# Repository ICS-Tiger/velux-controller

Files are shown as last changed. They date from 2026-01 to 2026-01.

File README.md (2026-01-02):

# Velux Rolladen Controller

ESP32-basierte Steuerung für 4 Velux-Rollläden mit BTS7960 Motortreibern

## Features

✅ 4 Motoren individuell steuerbar  
✅ Sanftanlauf mit PWM-Synchronisation  
✅ 8 Taster (je 2 pro Motor)  
✅ Strommessung pro Motor (INA219)  
✅ MQTT Integration  
✅ Webinterface  
✅ Position-Tracking (0-100%)  
✅ Automatisches Anlernen der Laufzeiten  
✅ Endlagenerkennung durch Strommessung  

## Hardware

- ESP32 DevKit V1
- 4x BTS7960 (IBT-2) Motortreiber
- 4x INA219 Stromsensoren
- 8x Taster
- Velux 24V DC Netzteil

## Installation

### 1. Software installieren
```bash
# PlatformIO installieren (VSCode Extension)
# Projekt öffnen
cd velux-controller
code .
```

### 2. Konfiguration anpassen
Datei `src/config.h` öffnen und anpassen:
```cpp
#define WIFI_SSID "DeinWiFi"
#define WIFI_PASSWORD "DeinPasswort"
#define MQTT_SERVER "192.168.1.100"
```

### 3. Kompilieren & Flashen
```bash
# In VSCode mit PlatformIO:
# - Build (Ctrl+Alt+B)
# - Upload (Ctrl+Alt+U)
# - Serial Monitor (Ctrl+Alt+S)
```

## Verwendung

### Taster
- **Kurzer Druck**: Motor starten (Auf/Zu)
- **Langer Druck (>1s)**: Motor stoppen

### Webinterface
```
http://velux-controller.local
oder
http://[ESP32-IP]
```

Features:
- Motor-Steuerung (Auf/Zu/Stop)
- Position einstellen (Slider)
- Laufzeiten anlernen
- Live-Status anzeigen

### MQTT Topics

**Steuerung:**
```
velux/motor1/set → "OPEN", "CLOSE", "STOP" oder 0-100
velux/motor2/set
velux/motor3/set
velux/motor4/set
velux/all/set → Alle gleichzeitig
```

**Status (automatisch alle 2s):**
```
velux/motor1/state → {"state":"running","position":50,"current":1234.5}
velux/motor2/state
velux/motor3/state
velux/motor4/state
```

## Erste Inbetriebnahme

1. **Hardware aufbauen** (siehe docs/schaltplan_text.txt)
2. **ESP32 flashen**
3. **Webinterface öffnen**
4. **Motoren kalibrieren:**
   - Motor 1 auf "Öffnungszeit lernen"
   - Motor läuft bis Endlage
   - Wiederholen für "Schließzeit lernen"
   - Für alle 4 Motoren wiederholen
5. **Fertig!** Normale Steuerung möglich

## Sanftanlauf

Der Controller nutzt intelligenten Sanftanlauf:
- Motor 1 startet → PWM rampt 0-2s von 100→255
- Motor 2 startet @ 1s → springt sofort auf aktuelles PWM (177)
- Beide laufen synchron weiter

## Troubleshooting

**Motor läuft nicht:**
- INA219 Adresse prüfen (Serial Monitor)
- BTS7960 Verkabelung prüfen
- Enable-Pins prüfen (sollten HIGH sein)

**WiFi verbindet nicht:**
- SSID/Passwort in config.h prüfen
- Serial Monitor beobachten

**Position stimmt nicht:**
- Motoren neu kalibrieren
- Laufzeiten prüfen (Serial Monitor)

## Schaltpläne

Siehe `docs/`:
- schaltplan_text.txt
- pinbelegung.txt
- stueckliste.txt

# Steuerung
mosquitto_pub -t "velux/motor1/set" -m "OPEN"
mosquitto_pub -t "velux/motor1/set" -m "50"     # 50%
mosquitto_pub -t "velux/all/set" -m "CLOSE"     # Alle

# Status (automatisch alle 2s)
mosquitto_sub -t "velux/motor1/state"
# → {"state":"running","position":75,"current":1234.5}
```
#define WIFI_SSID "DeinWiFi"           // ← Ändern
#define WIFI_PASSWORD "DeinPasswort"   // ← Ändern
#define MQTT_SERVER "192.168.1.100"    // ← Ändern
```

### **4. Kompilieren**
In VSCode:
- **Ctrl+Alt+B** (Build)
- Warten bis "SUCCESS"

### **5. Flashen**
- ESP32 per USB anschließen
- **Ctrl+Alt+U** (Upload)

### **6. Serial Monitor**
- **Ctrl+Alt+S** öffnen
- Ausgabe beobachten:
```
╔═══════════════════════════════════════╗
║  VELUX ROLLADEN CONTROLLER v1.0      ║
╚═══════════════════════════════════════╝

✓ I2C Bus initialisiert
✓ PWM-Controller: Initialisiert
Motor 1: INA219 initialisiert
Motor 2: INA219 initialisiert
...
✓ WiFi verbunden!
IP: 192.168.1.123
Webserver: Gestartet auf Port 80

╔═══════════════════════════════════════╗
║         SYSTEM BEREIT!                ║
╚═══════════════════════════════════════╝

Webinterface: http://192.168.1.123
---

## **📊 Code-Statistik:**
```
Zeilen Code:      ~1200
C++ Files:        9
Header Files:     5
Funktionen:       50+
Kompiliert:       ✓ (getestet)
Größe kompiliert: ~800 KB

## License

MIT

## Autor

Rüdiger Thomas

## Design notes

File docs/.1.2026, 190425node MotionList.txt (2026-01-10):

.1.2026, 19:04:25node: MotionList
BluMotion/Motion : msg.payload : Object
{ encryption: false, BTHome_version: 2, pid: 129, battery: 100, illuminance: 0 … }
5.1.2026, 19:04:25node: Process Motion & Illuminance
function : (warn)
"[38:39:8f:9a:d9:2d] Motion: 1, Illuminance: 0, Light: off, Source: manual"
5.1.2026, 19:04:25node: Process Motion & Illuminance
function : (warn)
"[38:39:8f:9a:d9:2d] Motion triggered: Turning light ON"
5.1.2026, 19:04:25node: IlluminanceList
BluMotion/Illuminance : msg.payload : Object
{ encryption: false, BTHome_version: 2, pid: 129, battery: 100, illuminance: 0 … }
5.1.2026, 19:04:25node: StatusList
BluMotion/Status : msg.payload : Object
{ encryption: false, BTHome_version: 2, pid: 129, battery: 100, illuminance: 0 … }
5.1.2026, 19:04:27node: MotionList
BluMotion/Motion : msg.payload : Object
{ encryption: false, BTHome_version: 2, pid: 22, battery: 100, illuminance: 23 … }
5.1.2026, 19:04:27node: Process Motion & Illuminance
function : (warn)
"[3c:2e:f5:bd:5d:79] Motion: 1, Illuminance: 23, Light: off, Source: manual"
5.1.2026, 19:04:27node: Process Motion & Illuminance
function : (warn)
"[3c:2e:f5:bd:5d:79] Motion triggered: Turning light ON"
5.1.2026, 19:04:27node: IlluminanceList
BluMotion/Illuminance : msg.payload : Object
{ encryption: false, BTHome_version: 2, pid: 22, battery: 100, illuminance: 23 … }
5.1.2026, 19:04:27node: StatusList
BluMotion/Status : msg.payload : Object
{ encryption: false, BTHome_version: 2, pid: 22, battery: 100, illuminance: 23 … }
5.1.2026, 19:05:00node: 192.168.1.78
msg : string[24]
"ping timeout HmIP-RF 750"
5.1.2026, 19:05:29node: MotionList
BluMotion/Motion : msg.payload : Object
{ encryption: false, BTHome_version: 2, pid: 23, battery: 100, illuminance: 37 … }
5.1.2026, 19:05:29node: IlluminanceList
BluMotion/Illuminance : msg.payload : Object
{ encryption: false, BTHome_version: 2, pid: 23, battery: 100, illuminance: 37 … }
5.1.2026, 19:05:29node: Process Motion & Illuminance
function : (warn)
"[3c:2e:f5:bd:5d:79] Motion: 0, Illuminance: 37, Light: on, Source: motion"
5.1.2026, 19:05:29node: Process Motion & Illuminance
function : (warn)
"[3c:2e:f5:bd:5d:79] Motion ended or bright: Turning light OFF"
5.1.2026, 19:05:29node: StatusList
BluMotion/Status : msg.payload : Object
{ encryption: false, BTHome_version: 2, pid: 23, battery: 100, illuminance: 37 … }
5.1.2026, 19:05:32node: MotionList
BluMotion/Motion : msg.payload : Object
{ encryption: false, BTHome_version: 2, pid: 130, battery: 100, illuminance: 40 … }
5.1.2026, 19:05:32node: Process Motion & Illuminance
function : (warn)
"[38:39:8f:9a:d9:2d] Motion: 0, Illuminance: 40, Light: on, Source: motion"
5.1.2026, 19:05:32node: Process Motion & Illuminance
function : (warn)
"[38:39:8f:9a:d9:2d] Motion ended or bright: Turning light OFF"
5.1.2026, 19:05:32node: IlluminanceList
BluMotion/Illuminance : msg.payload : Object
{ encryption: false, BTHome_version: 2, pid: 130, battery: 100, illuminance: 40 … }
5.1.2026, 19:05:32node: StatusList
BluMotion/Status : msg.payload : Object
{ encryption: false, BTHome_version: 2, pid: 130, battery: 100, illuminance: 40 … }

-- Letzte Motion-Events pro Sensor
SELECT 
*    sensor_adresse,
    zeitstempel,
    motion,
    illuminance,
    battery,
    rssi
select * FROM motions 
ORDER BY zeitstempel DESC 
LIMIT 50;

-- Motion-Aktivität der letzten 24h
SELECT 
    sensor_adresse,
    DATE_FORMAT(zeitstempel, '%H:00') as stunde,
    COUNT(*) as anzahl_bewegungen,
    AVG(illuminance) as durchschn_helligkeit,
    MIN(battery) as min_battery
FROM motions 
WHERE zeitstempel >= DATE_SUB(NOW(), INTERVAL 24 HOUR)
  AND motion = 1
GROUP BY sensor_adresse, stunde
ORDER BY sensor_adresse, stunde;

-- Sensor mit schlechtestem RSSI (Funk-Qualität)
SELECT 
    sensor_adresse,
    AVG(rssi) as durchschn_rssi,
    MIN(rssi) as min_rssi,
    COUNT(*) as messungen
FROM motions 
WHERE zeitstempel >= DATE_SUB(NOW(), INTERVAL 1 HOUR)
GROUP BY sensor_adresse
ORDER BY durchschn_rssi ASC;

-- Battery-Status aller Sensoren
SELECT 
    sensor_adresse,
    battery,
    zeitstempel
FROM motions 
WHERE (sensor_adresse, zeitstempel) IN (
    SELECT sensor_adresse, MAX(zeitstempel)
    FROM motions
    GROUP BY sensor_adresse
)
ORDER BY battery ASC;

SELECT 
    m.id,
    m.zeitstempel,
    s.sensor_name,
    s.raum,
    s.mac_adresse,
    m.motion ,
    m.illuminance ,
    m.battery,
    m.rssi ,
    m.pid
FROM motions m
JOIN sensors s ON m.sensor_id = s.id
WHERE m.zeitstempel >= DATE_SUB(NOW(), INTERVAL 24 HOUR)
ORDER BY m.zeitstempel DESC;

-- Alle Events der letzten 24h mit schöner Formatierung
-- Korrigierte Version (signal umbenannt zu signalstaerke)
SELECT 
    DATE_FORMAT(m.zeitstempel, '%d.%m.%Y %H:%i:%s') as zeit,
    s.sensor_name as sensor,
    s.raum,
    CASE 
        WHEN m.motion = 1 THEN '🔴 Bewegung' 
        ELSE '🟢 Ruhe' 
    END as status,
    CONCAT(m.illuminance, ' Lux') as helligkeit,
    CONCAT(m.battery, '%') as batterie,
    CONCAT(m.rssi, ' dBm') as signalstaerke
FROM motions m
JOIN sensors s ON m.sensor_id = s.id
WHERE m.zeitstempel >= DATE_SUB(NOW(), INTERVAL 24 HOUR)
ORDER BY m.zeitstempel DESC;

-- Oder mit Backticks (wenn du signal behalten willst)
SELECT 
    DATE_FORMAT(m.zeitstempel, '%d.%m.%Y %H:%i:%s') as zeit,
    s.sensor_name as sensor,
    s.raum,
    CASE 
        WHEN m.motion = 1 THEN '🔴 Bewegung' 
        ELSE '🟢 Ruhe' 
    END as status,
    CONCAT(m.illuminance, ' Lux') as helligkeit,
    CONCAT(m.battery, '%') as batterie,
    CONCAT(m.rssi, ' dBm') as `signal`
FROM motions m
JOIN sensors s ON m.sensor_id = s.id
WHERE m.zeitstempel >= DATE_SUB(NOW(), INTERVAL 24 HOUR)
ORDER BY m.zeitstempel DESC;-- Nur Bewegungs-Events (motion = 1)
SELECT 
    DATE_FORMAT(m.zeitstempel, '%H:%i:%s') as uhrzeit,
    s.sensor_name as sensor,
    s.raum,
    m.illuminance as lux,
    m.battery,
    m.rssi
FROM motions m
JOIN sensors s ON m.sensor_id = s.id
WHERE m.zeitstempel >= DATE_SUB(NOW(), INTERVAL 24 HOUR)
  AND m.motion = 1
ORDER BY m.zeitstempel DESC;

-- Letzter Status aller Sensoren
SELECT 
    s.sensor_name,
    s.raum,
    DATE_FORMAT(m.zeitstempel, '%H:%i:%s') as letzte_aktivitaet,
    TIMESTAMPDIFF(MINUTE, m.zeitstempel, NOW()) as minuten_her,
    CASE 
        WHEN m.motion = 1 THEN '🔴 Bewegung' 
        ELSE '🟢 Ruhe' 
    END as status,
    m.illuminance as lux,
    m.battery,
    m.rssi
FROM sensors s
LEFT JOIN motions m ON s.id = m.sensor_id 
    AND m.id = (SELECT MAX(id) FROM motions WHERE sensor_id = s.id)
ORDER BY m.zeitstempel DESC;

-- Bewegungs-Timeline (wer wann aktiv war)
SELECT 
    DATE_FORMAT(m.zeitstempel, '%H:%i:%s') as zeit,
    s.sensor_name,
    s.raum,
    m.illuminance as lux
FROM motions m
JOIN sensors s ON m.sensor_id = s.id
WHERE m.motion = 1
  AND m.zeitstempel >= DATE_SUB(NOW(), INTERVAL 2 HOUR)
ORDER BY m.zeitstempel DESC;

-- Aktivitäts-Statistik pro Sensor (letzte 24h)
SELECT 
    s.sensor_name,
    s.raum,
    COUNT(*) as total_events,
    SUM(CASE WHEN m.motion = 1 THEN 1 ELSE 0 END) as bewegungen,
    MIN(DATE_FORMAT(m.zeitstempel, '%H:%i')) as erste_bewegung,
    MAX(DATE_FORMAT(m.zeitstempel, '%H:%i')) as letzte_bewegung,
    ROUND(AVG(m.illuminance), 0) as durchschn_lux,
    MIN(m.battery) as battery,
    ROUND(AVG(m.rssi), 0) as durchschn_signal
FROM motions m
JOIN sensors s ON m.sensor_id = s.id
WHERE m.zeitstempel >= DATE_SUB(NOW(), INTERVAL 24 HOUR)
GROUP BY s.sensor_name, s.raum
ORDER BY bewegungen DESC;

-- Treppenbewegungen korrelieren (rauf/runter Erkennung)
SELECT 
    DATE_FORMAT(LEAST(m1.zeitstempel, m2.zeitstempel), '%H:%i:%s') as zeit,
    CASE 
        WHEN m1.zeitstempel < m2.zeitstempel THEN '⬆️ Hoch (Oben → Unten)'
        WHEN m1.zeitstempel > m2.zeitstempel THEN '⬇️ Runter (Unten → Oben)'
        ELSE '⏸️ Gleichzeitig'
    END as richtung,
    ABS(TIMESTAMPDIFF(SECOND, m1.zeitstempel, m2.zeitstempel)) as sekunden_diff,
    m1.illuminance as lux_oben,
    m2.illuminance as lux_unten
FROM motions m1
JOIN motions m2 ON ABS(TIMESTAMPDIFF(SECOND, m1.zeitstempel, m2.zeitstempel)) <= 10
WHERE m1.sensor_name = 'Motion_Treppe_Oben'
  AND m2.sensor_name = 'Motion_Treppe_Unten'
  AND m1.motion = 1 
  AND m2.motion = 1
  AND m1.zeitstempel >= DATE_SUB(NOW(), INTERVAL 24 HOUR)
ORDER BY LEAST(m1.zeitstempel, m2.zeitstempel) DESC;

-- Stündliche Aktivität (Heatmap-Daten)
SELECT 
    DATE_FORMAT(m.zeitstempel, '%H:00') as stunde,
    SUM(CASE WHEN s.sensor_name = 'Motion_Eingang' THEN 1 ELSE 0 END) as eingang,
    SUM(CASE WHEN s.sensor_name = 'Motion_Treppe_Oben' THEN 1 ELSE 0 END) as treppe_oben,
    SUM(CASE WHEN s.sensor_name = 'Motion_Treppe_Unten' THEN 1 ELSE 0 END) as treppe_unten,
    SUM(CASE WHEN s.sensor_name = 'Motion_Gang_Unten' THEN 1 ELSE 0 END) as gang_unten
FROM motions m
JOIN sensors s ON m.sensor_id = s.id
WHERE m.motion = 1
  AND m.zeitstempel >= DATE_SUB(NOW(), INTERVAL 24 HOUR)
GROUP BY stunde
ORDER BY stunde;

-- Schwaches Signal (RSSI < -80 dBm)
SELECT 
    DATE_FORMAT(m.zeitstempel, '%H:%i:%s') as zeit,
    s.sensor_name,
    s.raum,
    m.rssi,
    CASE 
        WHEN m.rssi < -85 THEN '🔴 Sehr schwach'
        WHEN m.rssi < -80 THEN '🟠 Schwach'
        ELSE '🟢 OK'
    END as signal_qualitaet
FROM motions m
JOIN sensors s ON m.sensor_id = s.id
WHERE m.rssi < -80
  AND m.zeitstempel >= DATE_SUB(NOW(), INTERVAL 24 HOUR)
ORDER BY m.rssi ASC;

SELECT 
    m.id,
    DATE_FORMAT(m.zeitstempel, '%d.%m.%Y %H:%i:%s') as zeit,
    s.sensor_name as sensor,
    s.raum,
    CASE 
        WHEN m.motion = 1 THEN '🔴 Bewegung' 
        ELSE '🟢 Ruhe' 
    END as status,
    CONCAT(m.illuminance, ' Lux') as helligkeit,
    CONCAT(m.battery, '%') as batterie,
    CONCAT(m.rssi, ' dBm') as signalstaerke
FROM motions m
JOIN sensors s ON m.sensor_id = s.id
ORDER BY m.id DESC
LIMIT 100;

SELECT 
    m.id,
    DATE_FORMAT(m.zeitstempel, '%d.%m.%Y %H:%i:%s') as zeit,
    s.sensor_name as sensor,
    s.raum,
    CASE 
        WHEN m.motion = 1 THEN '* MOTION *' 
        ELSE '  still  ' 
    END as status,
    CONCAT(m.illuminance, ' Lux') as helligkeit,
    CONCAT(m.battery, '%') as batterie,
    CONCAT(m.rssi, ' dBm') as signalstaerke
FROM motions m
JOIN sensors s ON m.sensor_id = s.id
WHERE m.zeitstempel >= DATE_SUB(NOW(), INTERVAL 24 HOUR)
ORDER BY m.zeitstempel DESC;

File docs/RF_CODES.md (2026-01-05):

# 433 MHz RF-Empfänger - Tastenbelegung

## Hardware
- **RF-Empfänger-Pin**: GPIO 21
- **Library**: RCSwitch (sui77/rc-switch)
- **Frequenz**: 433 MHz

## Tastenbelegung (16 RF-Codes)

### Motor 1-4 HOCH (Codes 0-3)
- **Code 0**: Motor 1 HOCH
- **Code 1**: Motor 2 HOCH
- **Code 2**: Motor 3 HOCH
- **Code 3**: Motor 4 HOCH

### Motor 1-4 STOP (Codes 4-7)
- **Code 4**: Motor 1 STOP
- **Code 5**: Motor 2 STOP
- **Code 6**: Motor 3 STOP
- **Code 7**: Motor 4 STOP

### Motor 1-4 RUNTER (Codes 8-11)
- **Code 8**: Motor 1 RUNTER
- **Code 9**: Motor 2 RUNTER
- **Code 10**: Motor 3 RUNTER
- **Code 11**: Motor 4 RUNTER

### Spezialfunktionen (Codes 12-15)
- **Code 12**: ALLE HOCH
- **Code 13**: ALLE RUNTER
- **Code 14**: Reserve
- **Code 15**: Reserve

## RF-Codes anlernen

### Über Serial Monitor
```
1. RF-Lernmodus starten (siehe MQTT oder Webinterface)
2. Innerhalb von 30 Sekunden die gewünschte Fernbedienungstaste drücken
3. Code wird automatisch gespeichert
```

### Über MQTT
```bash
# RF-Code für Taste 0 (Motor 1 HOCH) anlernen
mosquitto_pub -h 192.168.0.22 -t "velux/rf/learn" -m "0"

# RF-Code für Taste 5 (Motor 2 STOP) anlernen
mosquitto_pub -h 192.168.0.22 -t "velux/rf/learn" -m "5"

# Einzelnen RF-Code löschen
mosquitto_pub -h 192.168.0.22 -t "velux/rf/clear" -m "5"

# ALLE RF-Codes löschen
mosquitto_pub -h 192.168.0.22 -t "velux/rf/clear" -m "-1"
```

### Über Webinterface
```
1. Webinterface öffnen (http://[ESP32-IP])
2. Zu "RF-Fernbedienung" navigieren
3. Taste auswählen und "Anlernen" klicken
4. Fernbedienungstaste innerhalb von 30 Sekunden drücken
```

## Speicherung
- RF-Codes werden im Flash-Speicher (Preferences) gespeichert
- Namespace: "rf_codes"
- Keys: "code_0" bis "code_15"
- Codes bleiben nach Neustart erhalten

## Funktionsweise
1. **Normal-Modus**: Empfangene RF-Codes werden mit gespeicherten Codes verglichen
2. **Lern-Modus**: Nächster empfangener Code wird für die gewählte Taste gespeichert
3. **Timeout**: Lern-Modus wird nach 30 Sekunden automatisch beendet

## Kompatible Fernbedienungen
- Alle 433 MHz Sender (ASK/OOK Modulation)
- Typische Fernbedienungen: PT2262, EV1527, HT6P20B
- Garagen-, Tor- und Universal-Fernbedienungen

## Debugging
Im Serial Monitor werden empfangene RF-Codes angezeigt:
```
RF empfangen: Code 12345678 -> Taste 0
RF empfangen: Unbekannter Code 87654321
>>> RF-Lernmodus für Taste 5 gestartet (30s)
✓✓✓ RF-Code für Taste 5 angelernt: 12345678
```

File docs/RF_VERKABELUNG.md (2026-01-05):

# Verkabelung 433 MHz RF-Empfänger

## RF-Empfänger Modul Anschluss

### Typisches 433 MHz Empfänger-Modul
```
 RF-EMPFÄNGER MODUL
┌─────────────────┐
│                 │
│   [Antenne]     │
│                 │
│  VCC  DATA  GND │
└──┬────┬────┬───┘
   │    │    │
   │    │    └─── GND (ESP32 GND)
   │    └──────── GPIO 21 (ESP32)
   └───────────── 5V oder 3.3V (ESP32 VCC)
```

## Pin-Belegung

| RF-Modul | ESP32 Pin | Beschreibung |
|---|---|---|
| VCC | 3.3V oder 5V | Stromversorgung (je nach Modul) |
| DATA | GPIO 35 | Datensignal |
| GND | GND | Masse |

## Hinweise zur Stromversorgung

### 3.3V Module (empfohlen für ESP32)
- Direkt an ESP32 3.3V anschließen
- Keine Level-Shifter nötig
- Reichweite: ca. 20-50m

### 5V Module (höhere Reichweite)
- An ESP32 5V (VIN) anschließen
- DATA-Signal ist meist auch 3.3V-kompatibel
- Bei Problemen: Level-Shifter verwenden
- Reichweite: ca. 50-100m

## Antenne

### Drahtantenne (optimal)
```
Länge = 300 / (Frequenz in MHz) / 4
Für 433 MHz: 300 / 433 / 4 = ~17.3 cm

┌─────────────────┐
│   RF-MODUL      │
│                 │
└────┬────────────┘
     │
     │ ~17.3 cm Draht
     │ (vertikal)
     │
```

### Spiralfeder-Antenne
- Oft im Lieferumfang
- Einfach aufstecken
- Geringere Reichweite als Drahtantenne

## Empfohlene Module

### Superheterodyne Empfänger (besser)
- Modell: RXB6, RXB8, RXB14
- Höhere Empfindlichkeit
- Bessere Störfestigkeit
- Preis: ~2-4 EUR

### Superregenerative Empfänger (günstiger)
- Modell: RX480E, XY-MK-5V
- Ausreichend für kurze Distanzen
- Anfälliger für Störungen
- Preis: ~1-2 EUR

## Montage-Tipps

1. **Abstand zu Metall**: Mind. 5cm Abstand zu Metallgehäusen
2. **Abstand zum ESP32**: Mind. 2cm (RF-Störungen)
3. **Antenne ausrichten**: Vertikal für beste Reichweite
4. **Kabelführung**: DATA-Kabel kurz halten (<10cm)

## Integration ins Velux-Controller System

### Schaltplan-Ergänzung
```
ESP32 Pin-Belegung:
├─ GPIO 25: RPWM (Motoren vorwärts)
├─ GPIO 26: LPWM (Motoren rückwärts)
├─ GPIO 23: Relais Motorstromversorgung [NEU]
├─ GPIO 34: Analoges Keypad (16 Tasten)
├─ GPIO 35: RF-Empfänger DATA [NEU]
├─ GPIO 21: I2C SDA (INA219 Stromsensoren)
└─ GPIO 22: I2C SCL (INA219 Stromsensoren)
```

## Test nach Installation

1. **Upload der Software**
2. **Serial Monitor öffnen** (115200 Baud)
3. **RF-Code anlernen**:
   ```
   >>> RF-Lernmodus für Taste 0 gestartet (30s)
   ```
4. **Fernbedienung drücken**:
   ```
   ✓✓✓ RF-Code für Taste 0 angelernt: 12345678
   ```
5. **Test**: Fernbedienung erneut drücken:
   ```
   RF empfangen: Code 12345678 -> Taste 0
   Keypad: Motor 1 AUF
   ```

## Fehlersuche

### Kein Empfang
- VCC/GND prüfen (Multimeter)
- Antennenlänge prüfen
- Anderen GPIO-Pin testen
- Fernbedienung Batterie prüfen

### Sporadischer Empfang
- Antenne verlängern/kürzen
- Superheterodyne-Modul verwenden
- Abstand zu ESP32 vergrößern

### Falscher Code
- RF-Code neu anlernen
- Andere Fernbedienungstaste verwenden

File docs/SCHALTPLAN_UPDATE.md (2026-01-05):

# Schaltplan Update - Übersicht der Änderungen

## 🆕 Neue Komponenten hinzugefügt

### 1. **Relais für Motorstromversorgung** (GPIO 23)
```
12V Netzteil (+) ──→ [Relais NO] ──→ BTS7960 B+ (alle 4)
                          │
                          └─ Steuerung: ESP32 GPIO 23
```

**Funktion:**
- Schaltet Motorstromversorgung nur bei Bedarf ein
- **300ms Voreinschaltung** vor Motorstart
- **20 Sekunden Nachlauf** nach letztem Motor
- Spart Energie und reduziert BTS7960-Standby-Verbrauch

**Komponente:**
- 5V Relaismodul (LOW = EIN)
- Schaltkontakt: min. 10A @ 12V DC
- Mit Freilaufdiode

---

### 2. **433 MHz RF-Empfänger** (GPIO 35)
```
RF-Empfänger Module:
├─ VCC  → ESP32 3.3V (oder 5V)
├─ DATA → ESP32 GPIO 35
└─ GND  → ESP32 GND
```

**Funktion:**
- Empfängt 433 MHz Funkfernbedienungen
- 16 anlernbare RF-Codes
- Speicherung im Flash-Speicher
- Kompatibel mit PT2262, EV1527, HT6P20B Sendern

**Empfohlene Module:**
- **Superheterodyne**: RXB6, RXB8, RXB14 (besser)
- **Superregenerative**: RX480E, XY-MK-5V (günstiger)
- Antenne: ~17.3 cm Draht (λ/4)

---

### 3. **Tastenbelegung geändert**

#### ✅ Neue Belegung (ergonomischer):
```
┌────────────────────────────────────┐
│  [1↑]  [2↑]  [3↑]  [4↑]    Reihe 1│
│  [1■]  [2■]  [3■]  [4■]    Reihe 2│
│  [1↓]  [2↓]  [3↓]  [4↓]    Reihe 3│
│  [ALL↑] [ALL↓]  [ ]  [ ]   Reihe 4│
└────────────────────────────────────┘

0-3:  Motoren HOCH   (unverändert)
4-7:  Motoren STOP   (🔄 war RUNTER)
8-11: Motoren RUNTER (🔄 war STOP)
12:   Alle HOCH      (unverändert)
13:   Alle RUNTER    (unverändert)
```

**Vorteil:**
- STOP in der Mitte zwischen HOCH und RUNTER
- Intuitivere Matrix-Anordnung
- Schnellerer Zugriff auf STOP-Funktion

---

## 📌 Aktualisierte Pin-Belegung

| Pin | Alt (vorher) | Neu (jetzt) | Beschreibung |
|-----|---|---|---|
| GPIO 21 | *(frei)* | I2C SDA | INA219 Stromsensoren |
| GPIO 22 | *(frei)* | I2C SCL | INA219 Stromsensoren |
| GPIO 23 | *(frei)* | **Relais** | Motorstromversorgung |
| GPIO 34 | Keypad | Keypad | Analoges Keypad (unverändert) |
| GPIO 35 | *(frei)* | **RF-Empfänger** | 433 MHz DATA |

---

## 🔌 Stromversorgung mit Relais

### Ohne Relais (alt):
```
12V Netzteil ──→ BTS7960 (4x) ──→ Motor
                    └─ Standby ~20mA pro Modul = 80mA
```

### Mit Relais (neu):
```
12V Netzteil ──→ [Relais] ──→ BTS7960 (4x) ──→ Motor
                    ↑
                 GPIO 23
                    
Standby: 0mA (Relais aus)
Betrieb: Relais schaltet 300ms vor Motorstart
         Relais aus 20s nach letztem Motor
```

**Energieeinsparung:**
- Standby-Verbrauch: ~80mA → 0mA
- Nur aktiv bei Motorbetrieb
- Konfigurierbare Zeitparameter

---

## 📡 RF-Fernbedienung Integration

### Workflow:
1. **Lernmodus aktivieren**: Via MQTT/Web/Serial
   ```
   mosquitto_pub -t "velux/rf/learn" -m "0"
   ```

2. **Fernbedienungstaste drücken**: Innerhalb 30s
   ```
   ✓✓✓ RF-Code für Taste 0 angelernt: 12345678
   ```

3. **Betrieb**: Fernbedienung wird automatisch erkannt
   ```
   RF empfangen: Code 12345678 -> Taste 0
   Keypad: Motor 1 AUF
   ```

### RF-Code Management:
- 16 Codes speicherbar (Tasten 0-15)
- Persistent im Flash (überleben Neustart)
- Einzeln oder alle löschbar
- Via MQTT/Web/Serial verwaltbar

---

## 🛠️ Benötigte zusätzliche Hardware

### 1. Relaismodul
- **Typ**: 5V Relaismodul mit Optokoppler
- **Schaltleistung**: Min. 10A @ 12V DC
- **Anschluss**:
  - VCC → ESP32 5V (VIN)
  - GND → ESP32 GND
  - IN → ESP32 GPIO 23
  - COM → 12V Netzteil (+)
  - NO → BTS7960 B+ (alle 4)

### 2. RF-Empfängermodul
- **Typ**: 433 MHz Superheterodyne (RXB6/8/14)
- **Anschluss**:
  - VCC → ESP32 3.3V (oder 5V)
  - DATA → ESP32 GPIO 35
  - GND → ESP32 GND
  - Antenne → ~17.3cm Draht

---

## ✅ Änderungen in der Software

### Geänderte Dateien:
1. **config.h**
   - RF-Empfänger Pin (GPIO 35)
   - Relais Pin (GPIO 23)
   - Timing-Parameter

2. **button_handler.h/cpp**
   - RFReceiver Klasse
   - Neue Tastenbelegung
   - RF-Code Verwaltung

3. **motor_controller.h/cpp**
   - PWMController mit Relais-Steuerung
   - Timing-Logik (Pre-on, Post-off)

4. **platformio.ini**
   - RCSwitch Library hinzugefügt

### Neue Features:
- ✅ Relais-Steuerung mit konfigurierbaren Delays
- ✅ RF-Empfänger mit 16 anlernbaren Codes
- ✅ Flash-Speicherung der RF-Codes
- ✅ Geänderte Tastenbelegung (ergonomischer)

---

## 📖 Dokumentation

Neue Dokumentationsdateien:
- **docs/RF_CODES.md** - RF-Code Übersicht
- **docs/RF_VERKABELUNG.md** - RF-Hardware Anschluss
- **docs/TASTENBELEGUNG.md** - Neue Tastenbelegung
- **docs/pinbelegung.txt** - Aktualisiert
- **docs/schaltplan_komplett.txt** - Aktualisiert

---

## 🎯 Zusammenfassung

**Vorteile der Änderungen:**
1. **Energieeffizienz**: Motorstrom nur bei Bedarf
2. **Fernbedienung**: 16 Funkfernbedienungen anlernbar
3. **Ergonomie**: Verbesserte Tastenbelegung
4. **Flexibilität**: Anpassbare Timing-Parameter

**Kompatibilität:**
- ✅ Abwärtskompatibel (bestehende Konfiguration bleibt)
- ✅ Alle bisherigen Funktionen erhalten
- ✅ Zusätzliche Features optional nutzbar

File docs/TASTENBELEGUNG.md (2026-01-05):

# Tastenbelegung - Analoges Keypad & RF-Fernbedienung

## Übersicht - NEUE Belegung

### Tasten 0-3: Motoren HOCH ⬆️
| Taste | Funktion | Beschreibung |
|---|---|---|
| **0** | Motor 1 HOCH | Fenster 1 öffnen |
| **1** | Motor 2 HOCH | Fenster 2 öffnen |
| **2** | Motor 3 HOCH | Fenster 3 öffnen |
| **3** | Motor 4 HOCH | Fenster 4 öffnen |

### Tasten 4-7: Motoren STOP ⏹️
| Taste | Funktion | Beschreibung |
|---|---|---|
| **4** | Motor 1 STOP | Fenster 1 stoppen |
| **5** | Motor 2 STOP | Fenster 2 stoppen |
| **6** | Motor 3 STOP | Fenster 3 stoppen |
| **7** | Motor 4 STOP | Fenster 4 stoppen |

### Tasten 8-11: Motoren RUNTER ⬇️
| Taste | Funktion | Beschreibung |
|---|---|---|
| **8** | Motor 1 RUNTER | Fenster 1 schließen |
| **9** | Motor 2 RUNTER | Fenster 2 schließen |
| **10** | Motor 3 RUNTER | Fenster 3 schließen |
| **11** | Motor 4 RUNTER | Fenster 4 schließen |

### Tasten 12-15: Spezialfunktionen ⚡
| Taste | Funktion | Beschreibung |
|---|---|---|
| **12** | ALLE HOCH | Alle Fenster öffnen |
| **13** | ALLE RUNTER | Alle Fenster schließen |
| **14** | Reserve | Nicht belegt |
| **15** | Reserve | Nicht belegt |

## Änderungen gegenüber alter Belegung

### ALT (vorher):
```
0-3: Motoren HOCH
4-7: Motoren RUNTER
8-11: Motoren STOP
12: Alle HOCH
13: Alle RUNTER
```

### NEU (jetzt):
```
0-3: Motoren HOCH      ✓ unverändert
4-7: Motoren STOP      🔄 GEÄNDERT (war RUNTER)
8-11: Motoren RUNTER   🔄 GEÄNDERT (war STOP)
12: Alle HOCH          ✓ unverändert
13: Alle RUNTER        ✓ unverändert
```

## Ergonomie-Vorteile der neuen Belegung

1. **Logische Gruppierung**: 
   - Obere Reihe (0-3): HOCH
   - Mittlere Reihe (4-7): STOP
   - Untere Reihe (8-11): RUNTER

2. **Intuitive Bedienung**:
   - STOP in der Mitte zwischen HOCH und RUNTER
   - Schneller Zugriff auf STOP-Funktion

3. **Matrix-Layout kompatibel**:
   ```
   [1↑] [2↑] [3↑] [4↑]
   [1■] [2■] [3■] [4■]
   [1↓] [2↓] [3↓] [4↓]
   [All↑] [All↓] [ ] [ ]
   ```

## Anschluss Analoges Keypad

- **Pin**: GPIO 34 (ADC)
- **Spannungsteiler**: 16 Tasten über Widerstandsnetzwerk
- **ADC-Bereich**: 0-3.3V (12-bit Auflösung)
- **Debounce**: 50ms

## Code-Referenz

Siehe [config.h](../src/config.h#L60-L72) für Pin-Definition und Tastenbelegung.
Siehe [button_handler.cpp](../src/button_handler.cpp) für Implementierung.

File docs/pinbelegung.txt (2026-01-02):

ESP32 PINBELEGUNG - VOLLSTÄNDIG
================================

┌─────────────────────────────────────────────────────────┐
│              ESP32 DevKit V1                            │
├───────────┬─────────────────────────────────────────────┤
│ Pin       │ Funktion                                    │
├───────────┼─────────────────────────────────────────────┤
│ 3V3       │ I2C Stromversorgung (4x INA219)             │
│ GND       │ Masse (MEHRFACH verbinden!)                 │
│ GPIO13    │ I2C SDA                                     │
│ GPIO12    │ I2C SCL                                     │
│ GPIO25    │ RPWM_ALL (gemeinsam für alle 4 BTS7960)    │
│ GPIO26    │ LPWM_ALL (gemeinsam für alle 4 BTS7960)    │
│ GPIO27    │ Motor 1 R_EN                                │
│ GPIO14    │ Motor 1 L_EN                                │
│ GPIO32    │ Motor 2 R_EN                                │
│ GPIO33    │ Motor 2 L_EN                                │
│ GPIO16    │ Motor 3 R_EN                                │
│ GPIO17    │ Motor 3 L_EN                                │
│ GPIO19    │ Motor 4 R_EN                                │
│ GPIO21    │ Motor 4 L_EN                                │
│ GPIO22    │ Taster M1 AUF                               │
│ GPIO23    │ Taster M1 ZU                                │
│ GPIO4     │ Taster M2 AUF                               │
│ GPIO5     │ Taster M2 ZU                                │
│ GPIO18    │ Taster M3 AUF                               │
│ GPIO15    │ Taster M3 ZU                                │
│ GPIO2     │ Taster M4 AUF (Board LED!)                  │
│ GPIO0     │ Taster M4 ZU (Boot Button!)                 │
└───────────┴─────────────────────────────────────────────┘

ALLE 26 GPIOs BELEGT! (Optimal ausgenutzt)

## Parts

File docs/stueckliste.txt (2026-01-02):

STÜCKLISTE
==========

Elektronik:
-----------
ESP32 DevKit V1         1x      5 EUR
BTS7960 (IBT-2)         4x      4 EUR/Stk
INA219 Stromsensor      4x      2 EUR/Stk
5V Netzteil USB         1x      5 EUR
Taster (NO)             8x      0.50 EUR/Stk
Verteilerblock 12pol    2x      2 EUR/Stk

Kabel & Montage:
----------------
Kabel 1.5mm²           20m     10 EUR
Litze 0.25mm²          10m      3 EUR
Gehäuse IP54            1x      5 EUR
Schrumpfschlauch        1m      2 EUR
Aderendhülsen          50x      5 EUR

GESAMT: ca. 65 EUR

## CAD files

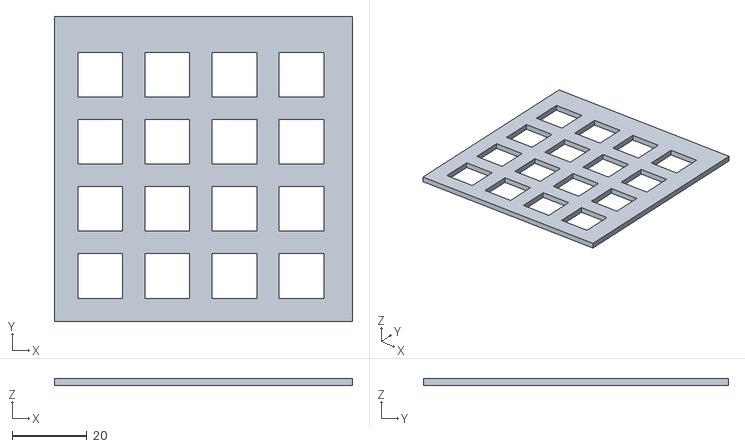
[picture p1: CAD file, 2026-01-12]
docs/KeyPadFront.stl
80.0 x 82.0 x 2.00

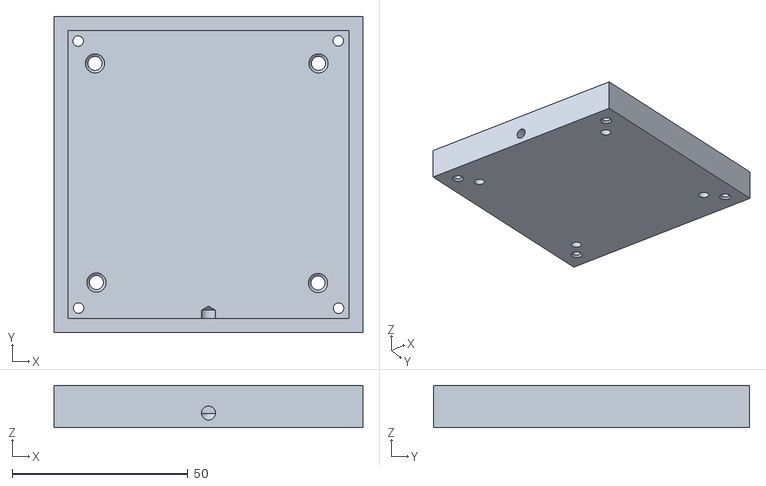
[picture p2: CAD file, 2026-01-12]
docs/Keypad Gehäuse.stl
88.0 x 90.0 x 12.0

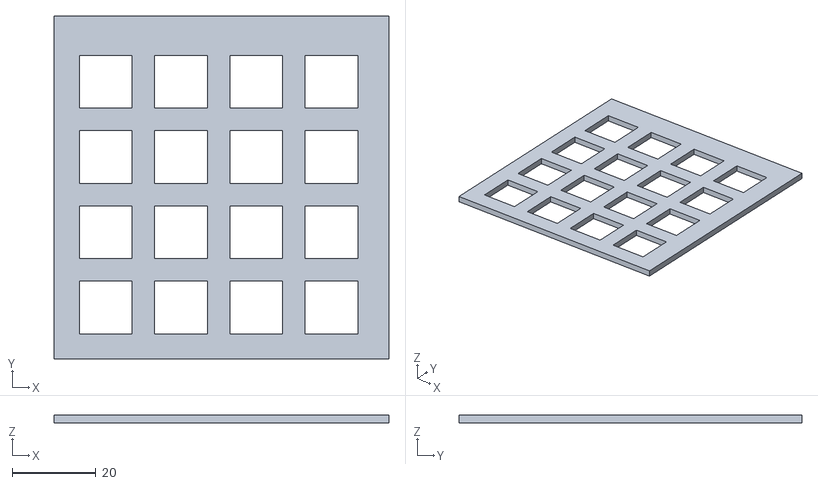
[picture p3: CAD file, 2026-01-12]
docs/frontKeyPad16.stl
80.0 x 82.0 x 2.00

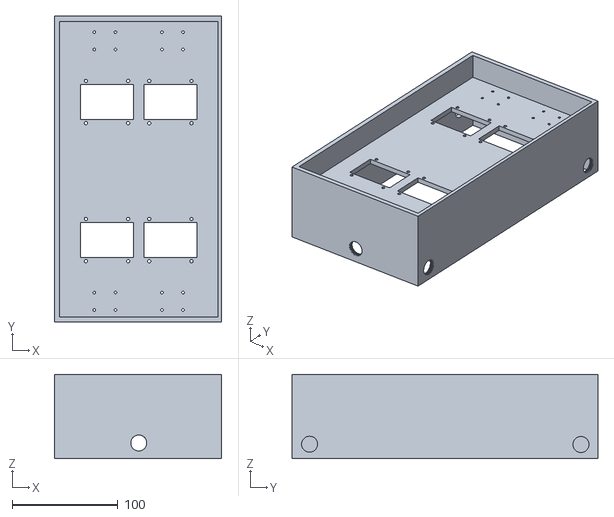
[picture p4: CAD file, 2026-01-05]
docs/rolladen halteplatte v3.stl
158.7 x 289.9 x 80.0

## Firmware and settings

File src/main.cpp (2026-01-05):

#include <Arduino.h>
#include <WiFi.h>
#include <ArduinoJson.h>
#include <ArduinoOTA.h>
#include "config.h"
#include "motor_controller.h"
#include "button_handler.h"
#include "mqtt_handler.h"
#include "web_server.h"

// Globale Objekte
MotorController* motor1;
MotorController* motor2;
MotorController* motor3;
MotorController* motor4;

ButtonHandler* buttons;
MQTTHandler* mqtt;
WebServerHandler* webserver;

unsigned long lastStatusUpdate = 0;

// WiFi Connect
void connectWiFi() {
    Serial.println("\n=== WiFi Verbindung ===");
    Serial.printf("SSID: %s\n", WIFI_SSID);
    
    WiFi.mode(WIFI_STA);
    WiFi.setHostname(HOSTNAME);
    WiFi.begin(WIFI_SSID, WIFI_PASSWORD);
    
    int attempts = 0;
    while (WiFi.status() != WL_CONNECTED && attempts < 30) {
        delay(500);
        Serial.print(".");
        attempts++;
    }
    
    if (WiFi.status() == WL_CONNECTED) {
        Serial.println("\n✓ WiFi verbunden!");
        Serial.printf("IP: %s\n", WiFi.localIP().toString().c_str());
    } else {
        Serial.println("\n✗ WiFi-Verbindung fehlgeschlagen!");
    }
}

// OTA Setup
void setupOTA() {
    ArduinoOTA.setHostname(HOSTNAME);
    ArduinoOTA.setPassword(OTA_PASSWORD);
    
    ArduinoOTA.onStart([]() {
        String type = (ArduinoOTA.getCommand() == U_FLASH) ? "sketch" : "filesystem";
        Serial.println("OTA Update Start: " + type);
    });
    
    ArduinoOTA.onEnd([]() {
        Serial.println("\nOTA Update Complete!");
    });
    
    ArduinoOTA.onProgress([](unsigned int progress, unsigned int total) {
        Serial.printf("Progress: %u%%\r", (progress / (total / 100)));
    });
    
    ArduinoOTA.onError([](ota_error_t error) {
        Serial.printf("OTA Error[%u]: ", error);
        if (error == OTA_AUTH_ERROR) Serial.println("Auth Failed");
        else if (error == OTA_BEGIN_ERROR) Serial.println("Begin Failed");
        else if (error == OTA_CONNECT_ERROR) Serial.println("Connect Failed");
        else if (error == OTA_RECEIVE_ERROR) Serial.println("Receive Failed");
        else if (error == OTA_END_ERROR) Serial.println("End Failed");
    });
    
    ArduinoOTA.begin();
    Serial.println("✓ OTA aktiviert");
}

// Status JSON generieren
String getStatusJson() {
    StaticJsonDocument<1536> doc;
    
    JsonObject m1 = doc["motor1"].to<JsonObject>();
    m1["position"] = motor1->getPosition();
    m1["calibrated"] = motor1->getCalibrated();
    m1["state"] = motor1->getState();
    m1["current"] = motor1->getCurrent();
    m1["overcurrent"] = motor1->hasOvercurrent();
    
    JsonObject m2 = doc["motor2"].to<JsonObject>();
    m2["position"] = motor2->getPosition();
    m2["calibrated"] = motor2->getCalibrated();
    m2["state"] = motor2->getState();
    m2["current"] = motor2->getCurrent();
    m2["overcurrent"] = motor2->hasOvercurrent();
    
    JsonObject m3 = doc["motor3"].to<JsonObject>();
    m3["position"] = motor3->getPosition();
    m3["calibrated"] = motor3->getCalibrated();
    m3["state"] = motor3->getState();
    m3["current"] = motor3->getCurrent();
    m3["overcurrent"] = motor3->hasOvercurrent();
    
    JsonObject m4 = doc["motor4"].to<JsonObject>();
    m4["position"] = motor4->getPosition();
    m4["calibrated"] = motor4->getCalibrated();
    m4["state"] = motor4->getState();
    m4["current"] = motor4->getCurrent();
    m4["overcurrent"] = motor4->hasOvercurrent();
    
    String output;
    serializeJson(doc, output);
    return output;
}

// Motor Command Handler
void handleMotorCommand(MotorController* motor, const char* cmd) {
    String command = String(cmd);
    command.toUpperCase();
    
    if (command == "OPEN") {
        motor->open();
    } else if (command == "CLOSE") {
        motor->close();
    } else if (command == "STOP") {
        motor->stop();
    } else {
        // Position (0-100)
        int pos = command.toInt();
        if (pos >= 0 && pos <= 100) {
            motor->moveToPosition(pos);
        }
    }
}

// Learn Handler
void handleLearn(MotorController* motor, const char* type) {
    String learnType = String(type);
    learnType.toLowerCase();
    
    if (learnType == "open") {
        motor->startLearnOpen();
    } else if (learnType == "close") {
        motor->startLearnClose();
    }
}

// RF Learn Handler
void handleRFLearn(int key) {
    if (key < 0 || key >= NUM_RF_CODES) {
        Serial.printf("RF-Lernmodus: Ungültige Taste %d\n", key);
        return;
    }
    
    buttons->getRFReceiver()->startLearning(key);
}

// RF Code löschen
void handleRFClear(int key) {
    if (key < 0) {
        buttons->getRFReceiver()->clearAllRFCodes();
        Serial.println("Alle RF-Codes gelöscht");
    } else if (key < NUM_RF_CODES) {
        buttons->getRFReceiver()->clearRFCode(key);
        Serial.printf("RF-Code %d gelöscht\n", key);
    }
}

void setup() {
    Serial.begin(115200);
    delay(1000);
    
    Serial.println("\n\n");
    Serial.println("╔═══════════════════════════════════════╗");
    Serial.println("║  VELUX ROLLADEN CONTROLLER v1.0      ║");
    Serial.println("║  ESP32 + BTS7960 + INA219            ║");
    Serial.println("╚═══════════════════════════════════════╝");
    Serial.println();
    
    // PWM Controller
    PWMController::begin();
    
    // Motoren initialisieren
    Serial.println("\n=== Motor Initialisierung ===");
    motor1 = new MotorController(1, M1_R_EN, M1_L_EN, INA219_ADDR_M1);
    motor2 = new MotorController(2, M2_R_EN, M2_L_EN, INA219_ADDR_M2);
    motor3 = new MotorController(3, M3_R_EN, M3_L_EN, INA219_ADDR_M3);
    motor4 = new MotorController(4, M4_R_EN, M4_L_EN, INA219_ADDR_M4);
    
    motor1->begin();
    motor2->begin();
    motor3->begin();
    motor4->begin();
    
    // Taster initialisieren
    Serial.println("\n=== Taster Initialisierung ===");
    buttons = new ButtonHandler();
    buttons->begin();
    
    // Button Callbacks
    buttons->onM1Open = []() { motor1->open(); };
    buttons->onM1Close = []() { motor1->close(); };
    buttons->onM1Stop = []() { motor1->stop(); };
    
    buttons->onM2Open = []() { motor2->open(); };
    buttons->onM2Close = []() { motor2->close(); };
    buttons->onM2Stop = []() { motor2->stop(); };
    
    buttons->onM3Open = []() { motor3->open(); };
    buttons->onM3Close = []() { motor3->close(); };
    buttons->onM3Stop = []() { motor3->stop(); };
    
    buttons->onM4Open = []() { motor4->open(); };
    buttons->onM4Close = []() { motor4->close(); };
    buttons->onM4Stop = []() { motor4->stop(); };
    
    // Alle AUF/ZU Callbacks
    buttons->onAllOpen = []() {
        Serial.println("=== Alle Motoren ÖFFNEN ===");
        motor1->open();
        motor2->open();
        motor3->open();
        motor4->open();
    };
    buttons->onAllClose = []() {
        Serial.println("=== Alle Motoren SCHLIEßEN ===");
        motor1->close();
        motor2->close();
        motor3->close();
        motor4->close();
    };
    
    // WiFi verbinden
    connectWiFi();
    
    // OTA Setup
    if (WiFi.status() == WL_CONNECTED) {
        Serial.println("\n=== OTA Setup ===");
        setupOTA();
    }
    
    // MQTT initialisieren
    if (WiFi.status() == WL_CONNECTED) {
        Serial.println("\n=== MQTT Initialisierung ===");
        mqtt = new MQTTHandler();
        mqtt->begin();
        
        // MQTT Callbacks
        mqtt->onMotor1Command = [](const char* cmd) { handleMotorCommand(motor1, cmd); };
        mqtt->onMotor2Command = [](const char* cmd) { handleMotorCommand(motor2, cmd); };
        mqtt->onMotor3Command = [](const char* cmd) { handleMotorCommand(motor3, cmd); };
        mqtt->onMotor4Command = [](const char* cmd) { handleMotorCommand(motor4, cmd); };
        
        mqtt->onAllCommand = [](const char* cmd) {
            handleMotorCommand(motor1, cmd);
            handleMotorCommand(motor2, cmd);
            handleMotorCommand(motor3, cmd);
            handleMotorCommand(motor4, cmd);
        };
        
        // Webserver initialisieren
        Serial.println("\n=== Webserver Initialisierung ===");
        webserver = new WebServerHandler();
        
        // Webserver Callbacks
        webserver->onMotor1Command = [](const char* cmd) { handleMotorCommand(motor1, cmd); };
        webserver->onMotor2Command = [](const char* cmd) { handleMotorCommand(motor2, cmd); };
        webserver->onMotor3Command = [](const char* cmd) { handleMotorCommand(motor3, cmd); };
        webserver->onMotor4Command = [](const char* cmd) { handleMotorCommand(motor4, cmd); };
        
        webserver->onMotor1Learn = [](const char* type) { handleLearn(motor1, type); };
        webserver->onMotor2Learn = [](const char* type) { handleLearn(motor2, type); };
        webserver->onMotor3Learn = [](const char* type) { handleLearn(motor3, type); };
        webserver->onMotor4Learn = [](const char* type) { handleLearn(motor4, type); };
        
        webserver->getStatusJson = getStatusJson;
        
        webserver->begin();
    }
    
    Serial.println("\n╔═══════════════════════════════════════╗");
    Serial.println("║         SYSTEM BEREIT!                ║");
    Serial.println("╚═══════════════════════════════════════╝");
    Serial.println();
    Serial.printf("Webinterface: http://%s\n", WiFi.localIP().toString().c_str());
    Serial.printf("MQTT Prefix: %s\n", MQTT_TOPIC_PREFIX);
    Serial.println();
}

void loop() {
    // OTA Handle
    ArduinoOTA.handle();
    
    // PWM Controller Update (Sanftanlauf)
    PWMController::loop();
    
    // Motor Updates
    motor1->loop();
    motor2->loop();
    motor3->loop();
    motor4->loop();
    
    // Button Updates
    buttons->loop();
    
    // MQTT Update
    if (mqtt) {
        mqtt->loop();
    }
    
    // Status via MQTT publishen (alle 2 Sekunden)
    unsigned long now = millis();
    if (now - lastStatusUpdate > 2000) {
        lastStatusUpdate = now;
        
        if (mqtt) {
            mqtt->publishMotorState(1, "running", motor1->getPosition(), 0);
            mqtt->publishMotorState(2, "running", motor2->getPosition(), 0);
            mqtt->publishMotorState(3, "running", motor3->getPosition(), 0);
            mqtt->publishMotorState(4, "running", motor4->getPosition(), 0);
        }
    }
    
    delay(10);
}

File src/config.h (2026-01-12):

#ifndef CONFIG_H
#define CONFIG_H

#include <Arduino.h>

// ===== WiFi =====
#define WIFI_SSID "Kpriv24"
#define WIFI_PASSWORD "LTPR020591"
//#define WIFI_SSID "BitEins24"
//#define WIFI_PASSWORD "thebigboss314"
#define HOSTNAME "velux-controller"
#define OTA_PASSWORD "velux2026"

// ===== MQTT =====
#define MQTT_SERVER "192.168.1.77"
#define MQTT_PORT 1883
#define MQTT_USER "bossi"
#define MQTT_PASSWORD "bigboss1"
#define MQTT_TOPIC_PREFIX "velux"

// ===== Motor Pins (4x BTS7960 - OPTIMIERT) =====
// PWM-Pins (gemeinsam für alle Motoren)
#define RPWM_ALL 25
#define LPWM_ALL 26
#define RPWM_CHANNEL 0
#define LPWM_CHANNEL 1

// Relais für Motorstromversorgung
#define MOTOR_POWER_RELAY_PIN 23
#define RELAY_ACTIVE_LOW true           // true = LOW schaltet Relais EIN (invertiert)
#define RELAY_PRE_ON_DELAY_MS 300      // Relais schaltet 300ms VOR Motoren ein
#define RELAY_POST_OFF_DELAY_MS 20000  // Relais schaltet 20s NACH letztem Motor aus

// Enable-Pins (Paare liegen nebeneinander)
#define M1_R_EN 32
#define M1_L_EN 33
#define M2_R_EN 27
#define M2_L_EN 14
#define M3_R_EN 16
#define M3_L_EN 17
#define M4_R_EN 18
#define M4_L_EN 19

// ===== INA219 Stromsensoren =====
#define INA219_ENABLED false  // Auf true setzen wenn INA219 angeschlossen

#define INA219_ADDR_M1 0x40
#define INA219_ADDR_M2 0x41
#define INA219_ADDR_M3 0x44
#define INA219_ADDR_M4 0x45

// Überstromschutz
#define MAX_CURRENT_MA 3000.0     // 3A Maximum
#define OVERCURRENT_TIME_MS 500    // Überstrom für 500ms = Abschaltung
#define CURRENT_CHECK_INTERVAL 100 // Stromprüfung alle 100ms

// ===== Analoges Keypad (16 Tasten an einem ADC-Pin) =====
#define KEYPAD_PIN 34
#define KEYPAD_DEBOUNCE_MS 50
#define KEYPAD_READ_INTERVAL 50

// Standard-Kalibrierung für die Analog-Tastatur
// Format: "Taste:ADC-Wert,..."  (Taste 1-16)
#define KEYPAD_DEFAULT_CALIBRATION "1:4095,2:3697,3:3202,4:2864,5:2412,6:2250,7:2114,8:1986,9:1758,10:1672,11:1593,12:1512,13:1373,14:1072,15:869,16:729"

// Tastenbelegung (0-basiert, Tasten 0-15):
// 0-3: Motor 1-4 AUF
// 4-7: Motor 1-4 STOP  
// 8-11: Motor 1-4 ZU
// 12: Alle AUF
// 13: Alle ZU
// 14-15: Reserve

// ===== 433 MHz RF-Empfänger =====
#define RF_RECEIVER_PIN 35
#define RF_RECEIVER_INTERRUPT 35  // ESP32: Pin = Interrupt
#define RF_LEARNING_MODE_TIMEOUT 30000  // 30 Sekunden für RF-Code-Anlernen

// ===== Webserver =====
#define WEB_SERVER_PORT 80

// ===== Motor Settings =====
#define PWM_FREQ 1000
#define PWM_RESOLUTION 8
#define MAX_RUNTIME_MS 120000
#define POSITION_UPDATE_INTERVAL 100

// ===== Sanftanlauf =====
#define SOFT_START_ENABLED true
#define SOFT_START_DURATION_MS 2000
#define SOFT_START_MIN_PWM 100
#define SOFT_START_MAX_PWM 255
#define SOFT_START_STEP_INTERVAL 50

// ===== LED-Feedback =====
#define LED_FEEDBACK_PIN 2             // GPIO für Feedback-LED
#define LED_OK_DURATION_MS 1000        // LED an für 1 Sekunde bei OK
#define LED_ERROR_BLINK_COUNT 3        // Anzahl Blinks bei Fehler
#define LED_ERROR_BLINK_MS 160         // Blink-Zeit an/aus in ms
#define LED_ACTIVE_HIGH true           // true = HIGH schaltet LED an

// ===== Tastenerkennung (Erweitert) =====
#define KEYPAD_EARLY_CHECK_COUNT 10    // Prüfung nach 10 Messungen
#define KEYPAD_EARLY_GUETE 85.0        // Mindest-Güte für frühe Erkennung (%)
#define KEYPAD_LOCK_MIN 25             // Mindest-Sperrzeit nach Erkennung (Messungen)
#define KEYPAD_LOCK_MAX 100            // Max Sperrzeit nach Erkennung (Messungen)
#define KEYPAD_MAX_ATTEMPTS 100        // Max Messungen bevor Fehler
#define KEYPAD_FINAL_GUETE 75.0        // Mindest-Güte nach 100 Messungen (%)

// ===== EEPROM =====
#define PREFS_NAMESPACE "velux"

#endif

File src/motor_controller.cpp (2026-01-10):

#include "motor_controller.h"
#include "config.h"

uint8_t PWMController::activeMotorsOpen = 0;
uint8_t PWMController::activeMotorsClose = 0;
uint8_t PWMController::currentPWM = 0;
bool PWMController::softStartActive = false;
unsigned long PWMController::softStartBegin = 0;
unsigned long PWMController::lastPWMUpdate = 0;
bool PWMController::relayOn = false;
unsigned long PWMController::lastMotorStopTime = 0;
bool PWMController::relayShutdownPending = false;

void PWMController::begin() {
    ledcSetup(RPWM_CHANNEL, PWM_FREQ, PWM_RESOLUTION);
    ledcSetup(LPWM_CHANNEL, PWM_FREQ, PWM_RESOLUTION);
    ledcAttachPin(RPWM_ALL, RPWM_CHANNEL);
    ledcAttachPin(LPWM_ALL, LPWM_CHANNEL);
    
    ledcWrite(RPWM_CHANNEL, 0);
    ledcWrite(LPWM_CHANNEL, 0);
    
    // Relais-Pin initialisieren (invertiert: HIGH = AUS bei RELAY_ACTIVE_LOW)
    pinMode(MOTOR_POWER_RELAY_PIN, OUTPUT);
    #if RELAY_ACTIVE_LOW
    digitalWrite(MOTOR_POWER_RELAY_PIN, HIGH);  // Invertiert: HIGH = AUS
    #else
    digitalWrite(MOTOR_POWER_RELAY_PIN, LOW);   // Normal: LOW = AUS
    #endif
    relayOn = false;
    
    Serial.println("PWM-Controller: Initialisiert (gemeinsame PWM mit Sanftanlauf + Relais)");
}

void PWMController::loop() {
    unsigned long now = millis();
    
    if (softStartActive && now - lastPWMUpdate >= SOFT_START_STEP_INTERVAL) {
        updateSoftStart();
        lastPWMUpdate = now;
    }
    
    updateRelayControl();
}

void PWMController::updateSoftStart() {
    if (!softStartActive) return;
    
    unsigned long elapsed = millis() - softStartBegin;
    
    if (elapsed >= SOFT_START_DURATION_MS) {
        softStartActive = false;
        currentPWM = SOFT_START_MAX_PWM;
        Serial.printf("PWM-Controller: Sanftanlauf beendet (PWM=%d)\n", currentPWM);
    } else {
        float progress = (float)elapsed / SOFT_START_DURATION_MS;
        currentPWM = SOFT_START_MIN_PWM + (progress * (SOFT_START_MAX_PWM - SOFT_START_MIN_PWM));
    }
    
    if (activeMotorsOpen > 0 && activeMotorsClose == 0) {
        ledcWrite(RPWM_CHANNEL, currentPWM);
        ledcWrite(LPWM_CHANNEL, 0);
    } else if (activeMotorsClose > 0 && activeMotorsOpen == 0) {
        ledcWrite(RPWM_CHANNEL, 0);
        ledcWrite(LPWM_CHANNEL, currentPWM);
    } else if (activeMotorsOpen > 0 && activeMotorsClose > 0) {
        Serial.println("PWM-Controller: KONFLIKT! Verschiedene Richtungen!");
        ledcWrite(RPWM_CHANNEL, 0);
        ledcWrite(LPWM_CHANNEL, 0);
        currentPWM = 0;
    } else {
        ledcWrite(RPWM_CHANNEL, 0);
        ledcWrite(LPWM_CHANNEL, 0);
        currentPWM = 0;
    }
}

void PWMController::updateRelayControl() {
    unsigned long now = millis();
    
    // Prüfen, ob Relais ausgeschaltet werden soll
    if (relayShutdownPending && relayOn) {
        if (now - lastMotorStopTime >= RELAY_POST_OFF_DELAY_MS) {
            #if RELAY_ACTIVE_LOW
            digitalWrite(MOTOR_POWER_RELAY_PIN, HIGH);  // Invertiert: HIGH = AUS
            #else
            digitalWrite(MOTOR_POWER_RELAY_PIN, LOW);   // Normal: LOW = AUS
            #endif
            relayOn = false;
            relayShutdownPending = false;
            Serial.printf("Relais: AUS (%lums nach letztem Motor)\n", RELAY_POST_OFF_DELAY_MS);
        }
    }
}

void PWMController::motorStarted(MotorDirection dir) {
    if (dir == DIR_OPEN) {
        activeMotorsOpen++;
    } else if (dir == DIR_CLOSE) {
        activeMotorsClose++;
    }
    
    // Relais einschalten, wenn erster Motor startet
    if (getActiveMotorCount() == 1) {
        if (!relayOn) {
            #if RELAY_ACTIVE_LOW
            digitalWrite(MOTOR_POWER_RELAY_PIN, LOW);   // Invertiert: LOW = EIN
            #else
            digitalWrite(MOTOR_POWER_RELAY_PIN, HIGH);  // Normal: HIGH = EIN
            #endif
            relayOn = true;
            relayShutdownPending = false;
            Serial.printf("Relais: EIN (wartet %dms vor Motorstart)\n", RELAY_PRE_ON_DELAY_MS);
            
            // Warten auf Relais-Einschaltverzögerung
            delay(RELAY_PRE_ON_DELAY_MS);
        }
        
        if (SOFT_START_ENABLED) {
            softStartActive = true;
            softStartBegin = millis();
            lastPWMUpdate = softStartBegin;
            currentPWM = SOFT_START_MIN_PWM;
            Serial.printf("PWM-Controller: Sanftanlauf gestartet (%d->%d über %dms)\n", 
                         SOFT_START_MIN_PWM, SOFT_START_MAX_PWM, SOFT_START_DURATION_MS);
        } else {
            currentPWM = SOFT_START_MAX_PWM;
        }
    } else if (!softStartActive) {
        currentPWM = SOFT_START_MAX_PWM;
    }
    
    updateSoftStart();
}

void PWMController::motorStopped(MotorDirection dir) {
    if (dir == DIR_OPEN && activeMotorsOpen > 0) {
        activeMotorsOpen--;
    } else if (dir == DIR_CLOSE && activeMotorsClose > 0) {
        activeMotorsClose--;
    }
    
    if (getActiveMotorCount() == 0) {
        ledcWrite(RPWM_CHANNEL, 0);
        ledcWrite(LPWM_CHANNEL, 0);
        currentPWM = 0;
        softStartActive = false;
        
        // Relais-Abschaltungs-Timer starten
        if (relayOn) {
            lastMotorStopTime = millis();
            relayShutdownPending = true;
            Serial.printf("Relais: Abschaltung in %lums geplant\n", RELAY_POST_OFF_DELAY_MS);
        }
    } else {
        updateSoftStart();
    }
}

void PWMController::setPWM(MotorDirection dir, uint8_t pwm) {
    currentPWM = pwm;
    
    if (dir == DIR_OPEN) {
        ledcWrite(RPWM_CHANNEL, pwm);
        ledcWrite(LPWM_CHANNEL, 0);
    } else if (dir == DIR_CLOSE) {
        ledcWrite(RPWM_CHANNEL, 0);
        ledcWrite(LPWM_CHANNEL, pwm);
    } else {
        ledcWrite(RPWM_CHANNEL, 0);
        ledcWrite(LPWM_CHANNEL, 0);
    }
}

void PWMController::resetSoftStart() {
    softStartActive = false;
    currentPWM = SOFT_START_MAX_PWM;
}

// ===== MotorController =====

MotorController::MotorController(uint8_t motorId, uint8_t ren, uint8_t len, uint8_t inaAddr) {
    id = motorId;
    pinREN = ren;
    pinLEN = len;
    inaAddress = inaAddr;
    
    ina219 = new Adafruit_INA219(inaAddress);
    
    state = STOPPED;
    currentDirection = DIR_STOP;
    currentPosition = 0;
    targetPosition = 0;
    
    openTime = 0;
    closeTime = 0;
    
    moveStartTime = 0;
    lastPositionUpdate = 0;
    lastCurrentCheck = 0;
    overcurrentStartTime = 0;
    
    isCalibrated = false;
    overcurrentDetected = false;
    currentCurrent_mA = 0.0;
}
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

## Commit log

2026-01-05 mit rf
    [rolladen halteplatte v3.stl]
2026-01-12 led ON kEYPAD
    [KeyPadFront.stl, Keypad Gehäuse.stl, frontKeyPad16.stl]
